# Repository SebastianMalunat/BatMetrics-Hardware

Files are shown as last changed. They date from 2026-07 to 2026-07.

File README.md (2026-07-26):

# BatMetrics — Hardware & Firmware

*Open-source, low-cost hardware and firmware for automated, low-disturbance bat activity monitoring.*



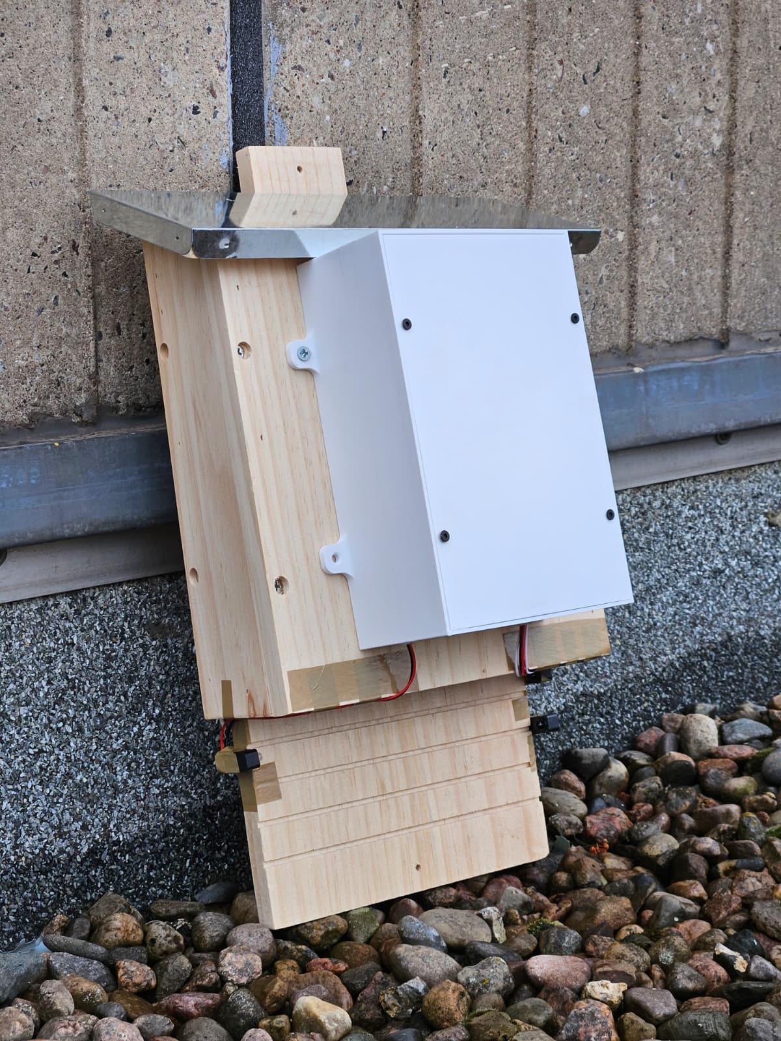
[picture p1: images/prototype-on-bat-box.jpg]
BatMetrics prototype installed on a bat box


## Table of contents

- [Overview](#overview)
- [How it works](#how-it-works)
- [Hardware overview](#hardware-overview)
- [Firmware setup](#firmware-setup)
- [Data & BLE protocol](#data--ble-protocol)
- [Enclosure](#enclosure)
- [Companion app](#companion-app)
- [Limitations](#limitations)
- [License](#license)
- [Acknowledgments](#acknowledgments)

## Overview

BatMetrics is a retrofittable sensor unit for bat boxes. Two infrared beam-break sensors at the box entrance count individual bats entering and leaving, while an onboard temperature and humidity sensor tracks conditions outside the box. Counts and readings are logged to a micro SD card and made available live over Bluetooth Low Energy, so data can be checked and exported without opening the box.

The project aims to make basic bat activity monitoring affordable and accessible to small conservation groups and researchers, in support of UN SDG 15 (Life on Land).

This repository holds the hardware design and Arduino firmware. For the mobile-friendly dashboard that syncs with it, see the [BatMetrics app repository](https://github.com/antoniabuss/bat-metrics-application).

## How it works

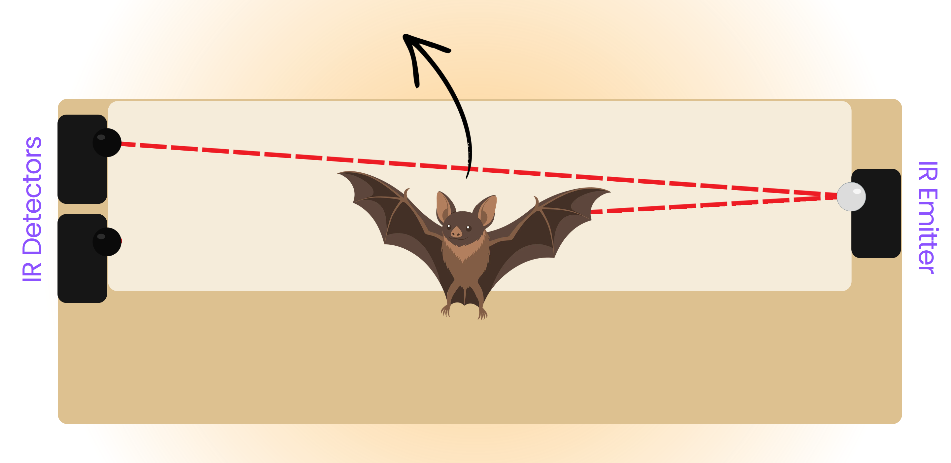
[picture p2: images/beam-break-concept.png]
Beam-break counting concept


Two IR receivers are mounted vertically at the box entrance, opposite a single IR emitter operating at 950 nm (outside the visible range for common bat species). Under normal conditions both beams stay unbroken. When a bat crosses, its body interrupts one beam slightly before the other — the order the beams break in determines direction: sensor-1-first is counted as **in**, sensor-2-first as **out**. If both beams break within the same debounced sample (e.g. two bats passing at once), the event is logged separately as **unknown** rather than guessing a direction.

A short per-beam debounce (15 ms, tuned against real bounce measurements) filters out spurious transitions before they're trusted, and a four-state sequence (`IDLE` → `ARMED_1`/`ARMED_2` → `CLEARING`) prevents a single bat lingering at the entrance from being counted twice.

Temperature and humidity are sampled once at boot and then every 15 minutes. Every confirmed crossing and every sensor reading is written to the SD card immediately, and pushed to any connected BLE client without delay.

## Hardware overview

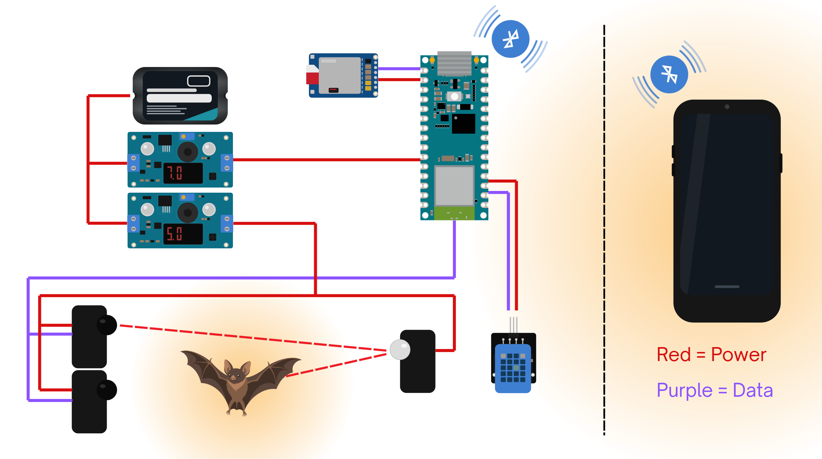
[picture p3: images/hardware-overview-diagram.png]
Hardware overview diagram


*Red = power, purple = data.*

The system has three hardware groups:

- **Sensor array** — two IR beam-break receivers and one IR emitter at the box entrance.
- **Microcontroller & storage** — an Arduino Nano ESP32 reads the sensors, drives BLE, and logs to a micro SD card over SPI.
- **Power supply** — a single 2S Li-ion pack feeds two step-down converters (7 V for the Arduino, 5 V for the IR sensors/emitter).

Full bill of materials, wiring tables, and step-by-step build instructions: **[docs/HARDWARE.md](docs/HARDWARE.md)**.

## Firmware setup

### Requirements

- [Arduino IDE](https://www.arduino.cc/en/software) with the **esp32** board package installed (via Boards Manager)
- Board: **Arduino Nano ESP32**
- Library: **DHT11** (the lightweight library exposing `readTemperatureHumidity()` / `setDelay()` / `getErrorString()` — install via Library Manager and confirm it matches this API before flashing, since multiple same-named DHT libraries with different interfaces exist)
- `SPI`, `SD`, `BLEDevice`, `BLEServer`, `BLEUtils`, `BLE2902` — bundled with the ESP32 board package, no separate install needed
- A micro SD card formatted as **FAT32** (32 GB or smaller — larger cards caused issues during development)

### Flashing

1. Clone this repository:
   ```
   git clone https://github.com/SebastianMalunat/BatMetrics-Hardware.git
   ```
2. Open `batmetrics_firmware.ino` in the Arduino IDE.
3. Select **Tools → Board → Arduino Nano ESP32**.
4. Connect the Arduino via USB-C and select the matching **Port**.
5. Verify/compile, then upload.
6. Open the Serial Monitor at **115200 baud** to see live beam states and counts for debugging.

The BLE device name is set in the `BLEDevice::init(...)` call near the top of `setup()` — rename it (e.g. to identify each deployed box) before flashing your own unit.

## Data & BLE protocol

### SD card snapshot

The current counts and latest environmental reading are written to `/COUNTS.CSV` on every event, overwriting the previous snapshot (not an append-only log):

```
count_in,count_out,count_unknown,net,temperature,humidity,uptime_millis
```

`net` is `count_in - count_out`; `count_unknown` counts crossings where a direction couldn't be reliably assigned.

### BLE characteristic

The Arduino advertises as a BLE peripheral under a configurable name (`BatBox-<name>`) with one service/characteristic pair:

| | UUID |
|---|---|
| Service | `12345678-1234-1234-1234-1234567890ab` |
| Characteristic | `abcd1234-1234-1234-1234-1234567890ab` |

The characteristic supports both **read** (current value) and **notify** (pushed on every counted crossing and every temperature/humidity reading), and holds a compact JSON payload:

```json
{"bats": 12, "temp": 21.5, "hum": 63}
```

`bats` is the net count (`count_in - count_out`). A newly connected client receives an immediate update rather than waiting for the next event.

## Enclosure

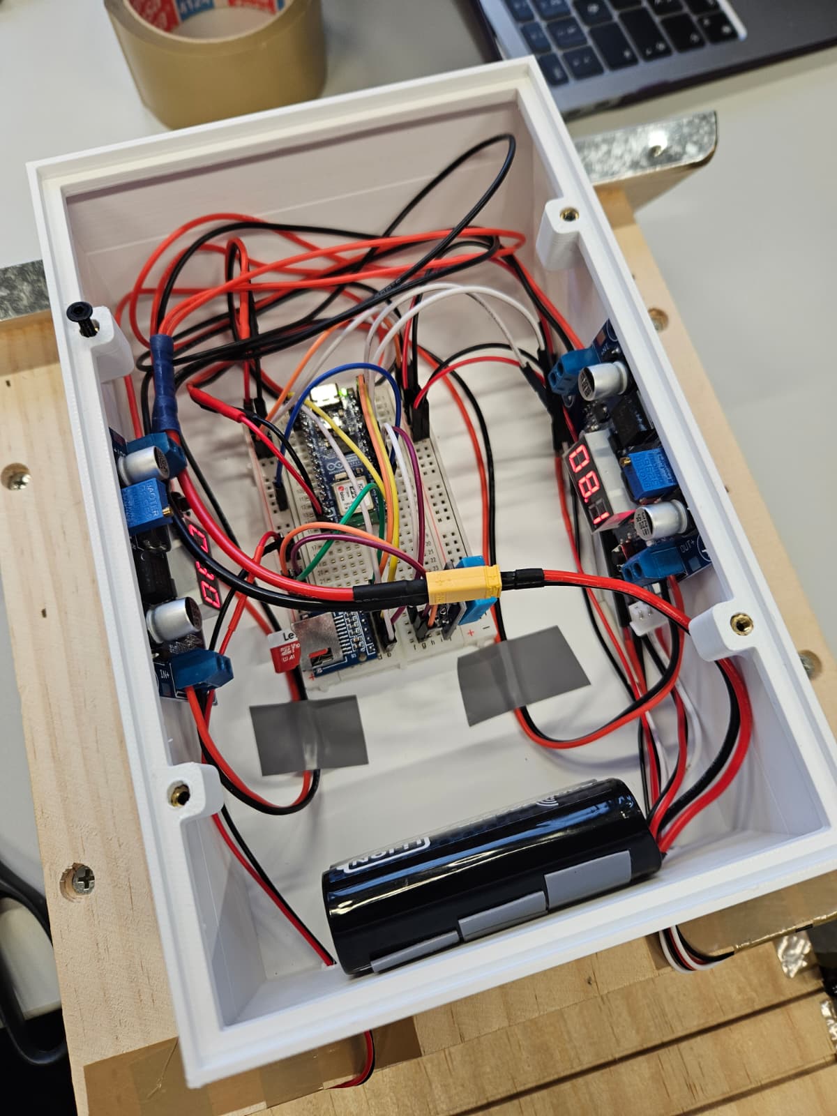
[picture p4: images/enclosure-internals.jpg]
Assembled electronics inside the enclosure

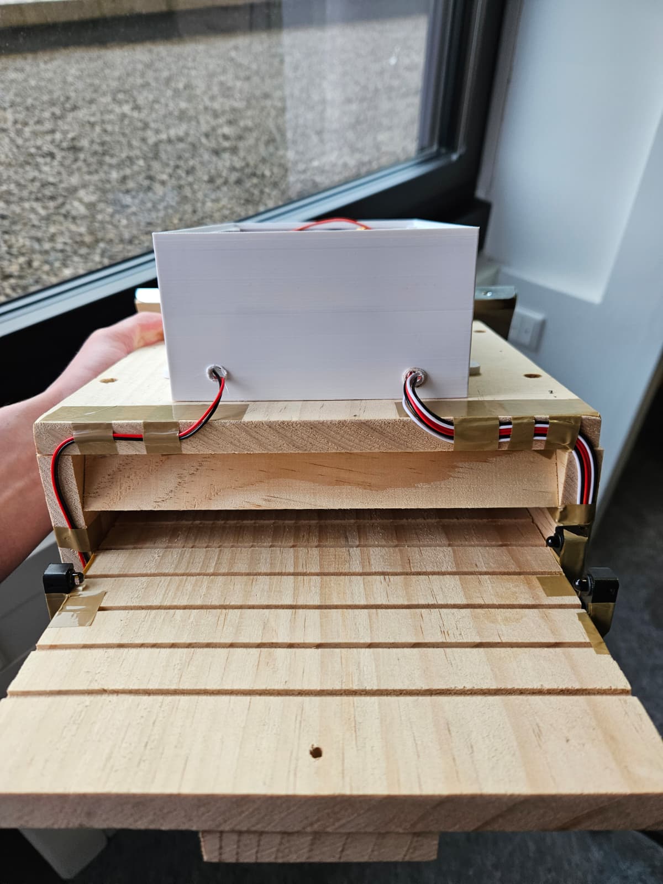
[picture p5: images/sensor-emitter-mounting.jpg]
IR sensor and emitter mounted at the box entrance


The electronics are housed in a 3D-printed, two-part enclosure (body + lid) that mounts directly onto a bat box via four screw tabs. The prototype housing is deliberately oversized to simplify assembly — a production version could be considerably smaller — and future iterations should add weatherproofing (e.g. a rubber seal) and dedicated mounts for the internal electronics, which are currently glued in place.

Source files (`.3mf`) for both parts are in [`enclosure/`](enclosure/); we printed ours in PLA with heat-set inserts for the lid screws. The editable CAD model is available on [Onshape](https://cad.onshape.com/documents/98fc3c93e9cfa1a28dc60713/w/ab1f05b3e45a61a059b0592a/e/94952d4c4642f22f709c8d5e).

## Companion app

The [BatMetrics app](https://github.com/antoniabuss/bat-metrics-application) is the client-side dashboard used to sync a box, view its readings, and export data as CSV. It connects over Web Bluetooth, which restricts it to Chromium-based browsers (Chrome, Edge) — Firefox and Safari aren't supported.

## Limitations

- **Environmental sensing** — the DHT11 sensor is rated 0–50 °C; winter outdoor deployment would need a sensor rated for sub-zero temperatures.
- **Weather resistance** — neither the enclosure nor the IR components are weatherproofed yet; sealing and potted wire passthroughs are needed for permanent outdoor use.
- **Power supply** — the 2S Li-ion pack performed well in testing but doesn't offer the runtime needed for prolonged unattended deployment; a long-runtime, weather-resistant power solution is future work.
- **Step-down converter noise** — the converters used occasionally emit a high-pitched noise that could potentially disturb bats; quieter alternatives should be evaluated.
- **Counting robustness** — validated reliably under lab conditions with two sensors; real-world conditions may be more challenging, and additional sensors could improve robustness.

The companion app has its own set of limitations (no backend, browser-local storage only) — see its [README](https://github.com/antoniabuss/bat-metrics-application#limitations).

## License

This project — including the firmware, hardware design files, and documentation — is licensed under the [MIT License](LICENSE).

## Acknowledgments

Developed as part of the Digital Innovation Lab at Universität Hamburg.

Issues and pull requests are welcome.

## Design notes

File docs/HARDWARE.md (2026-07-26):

# Hardware guide

Full bill of materials, wiring tables, and build instructions for the BatMetrics sensor unit. See the [main README](../README.md) for an overview of how the system works.

Building this requires basic soldering/crimping skills but is approachable for most makers. Total build cost is under €200 for a single unit, or under €150 per unit when building several.

## Table of contents

- [Bill of materials](#bill-of-materials)
- [Wiring tables](#wiring-tables)
- [Build instructions](#build-instructions)

## Bill of materials

| # | Qty | Manufacturer | Part | Description | Approx. cost/unit |
|---|---|---|---|---|---|
| 1 | 1 | Arduino | Nano ESP32 (with headers) | Microcontroller used for the counting system | 22€ |
| 2 | 2 | Adafruit | ADA2168 (5 mm) | IR beam-break sensors | 11€ |
| 3 | 2 | Generic (AZ-Delivery) | LM2596S | Step-down converters | 4€ |
| 4 | 1 | Radiomaster | 2S 21700 5000 mAh Li-ion | Battery | 25€ |
| 5 | 1 set | Generic (GTIWUNG) | Pre-soldered XT30 connector set with cables | Connectors and wires for power distribution | 8€ |
| 6 | 1 set | Generic (QWORK) | 22 AWG silicone wire set | Power cables for distributing power to components | 15€ |
| 7 | 1 set | Generic (ELEGOO) | Jumper cable set | Male-male, male-female, female-female jumper cables | 7€ |
| 8 | 1 | Generic (AZDelivery) | Mini breadboard, 400 pin | Breadboard | 4€ |
| 9 | 1 | Lexar | 32 GB UHS-I, U1, A1, V10, C10 micro SD card | Storage for config and occupancy data | 18€ |
| 10 | 1 | Generic (Create idea) | Micro SD card module, SPI, 3.3 V | Micro SD card module | 2€ |
| 11 | 1 | Generic (AZDelivery) | DHT11 temperature and humidity sensor | Temperature and humidity module | 5€ |
| 12 | 1 | Generic (WILDLIFE HOME) | Large wood bat box, built to NABU standards | Bat box | 30€ |
| 13 | 1 set | Generic | Wood screws | For attaching the 3D-printed housing to the bat box, and the IR emitter/sensors | <10€ |
| 14 | 1 set | Generic (Bolatus) | Heat-set inserts for 3D prints | For securing the housing's lid | 12€ |
| 15 | 1 set | Generic | Machine screw set (metric) | For securing the housing's lid | 11€ |

**Total cost per unit:** < €199
**Total cost per unit (building multiple systems):** < €145

## Wiring tables

### SD card module

| SD card module | Arduino Nano ESP32 |
|---|---|
| GND | Shared ground rail (or GND on the Arduino) |
| MISO | D12 (CIPO / GPIO047) |
| CLK | D13 (SCK / GPIO048) |
| MOSI | D11 (COPI / GPIO038) |
| CS | D4 (GPIO07) |
| 3V3 | 3V3 OUT |

### Temperature and humidity sensor

| DHT11 sensor | Arduino Nano ESP32 |
|---|---|
| I/O | D3 (GPIO06) |
| GND | Shared ground rail (or GND on the Arduino) |
| VCC | 3V3 OUT |

### IR beam-break sensors and emitter

| | IR sensor 1 | IR sensor 2 | IR emitter |
|---|---|---|---|
| 5V | 5V Out step-down converter (V OUT +) | 5V Out step-down converter (V OUT +) | 5V Out step-down converter (V OUT +) |
| GND | V OUT − (or shared ground rail) | V OUT − (or shared ground rail) | V OUT − (or shared ground rail) |
| DATA | Arduino D6 | Arduino D8 | — |

### Step-down converters

| 7V Out converter | Arduino Nano ESP32 |
|---|---|
| V OUT + | VIN |
| V OUT − | GND |

| 7V Out converter | Battery |
|---|---|
| V IN + | V OUT + |
| V IN − | V OUT − |

| 5V Out converter | 5V power rail on breadboard |
|---|---|
| V OUT + | + rail |
| V OUT − | − rail |

| 5V Out converter | Battery |
|---|---|
| V IN + | V OUT + |
| V IN − | V OUT − |

## Build instructions

Soldering and crimping are recommended for reliable connections; jumper cables and pin headers are usable for testing or to lower the barrier to entry (our prototype relies heavily on jumper cables to keep soldering to a minimum). Anyone building this system for actual deployment should replace jumper connections with soldered joints, crimps, or other more durable connections.

### Enclosure prep

1. 3D print the enclosure (we used PLA) — source files are in [`../enclosure/`](../enclosure/).
2. Drill one or two holes in the underside of the enclosure to pass the wires for the IR emitter and sensors through.
3. Install the four heat-set inserts into the corresponding holes in the print.
4. Glue the breadboard into the enclosure using its adhesive backing.
5. Glue the step-down converters to the inside of the enclosure. Future iterations should mount these more securely, e.g. with heat-set inserts and screws.

### Power wiring

Assembled electronics inside the enclosure

6. Build a power splitter cable by crimping a pre-soldered male XT30 connector to two red and two black silicone wires, so each wire from the connector splits into two. Tin the free ends to ease insertion into the step-down converters' terminals.
7. Connect one red/black pair from the splitter to the input of each step-down converter, following the wiring tables above.
8. Set one converter to output 7 V and the other 5 V. If the converters have a display, switch it to show output voltage and adjust the potentiometer accordingly; otherwise connect a battery to the input and adjust the potentiometer while measuring output with a multimeter. Labelling the underside of each converter helps keep track of which is which.
9. Solder jumper connectors to one end of two red and two black wire lengths, and tin the other ends.
10. Connect the 7 V converter's output to the Arduino and the ground rail using these wires.
11. Connect the 5 V converter's output to one of the breadboard's power rails using the second set of wires — this rail supplies 5 V to the remaining components and serves as the shared ground.

### Electronics and sensors

12. Place the Arduino on the breadboard, leaving enough space for the micro SD card module and the temperature/humidity sensor.
13. Place the micro SD card module on the breadboard and wire it per the table above.
14. Format the micro SD card as FAT32 and insert it into the module. Cards larger than 32 GB caused issues for us and should be avoided.
15. Place the temperature and humidity sensor on the breadboard and wire it per the table above.
16. Strip the wire ends of the IR emitter and both IR sensors, and solder jumper connectors onto each — we recommend covering the joints with heat shrink to prevent shorts. In a production build these should be wired directly to the Arduino, with leads extended as needed for the target bat box.

IR sensor and emitter mounted at the box entrance

17. Mount the IR emitter and both sensors at the entrance of the bat box, emitter on one side and both sensors on the other (e.g. sensors on the left, emitter on the right) — all three come with screw holes for this. Space the sensors approximately 3.5 cm apart vertically, measured at the sensor itself, to improve counting reliability.
18. Wire the IR emitter and both sensors to the Arduino and step-down converter per the table above.

### Firmware, assembly & testing

19. Clone this repository, install the required libraries (see the [main README](../README.md#requirements)), and compile/upload the firmware via the Arduino IDE.
20. Place the battery inside the enclosure and secure it (we used electrical tape).
21. Connect the battery's XT30 connector to the splitter's XT30 connector — the system should power up and begin counting.
22. Fit the lid and fasten the retaining screws.
23. Confirm proper operation by testing the Bluetooth connection with the app. Simulate bat crossings by hand at the entrance and verify the count updates correctly both in the app and on the micro SD card.

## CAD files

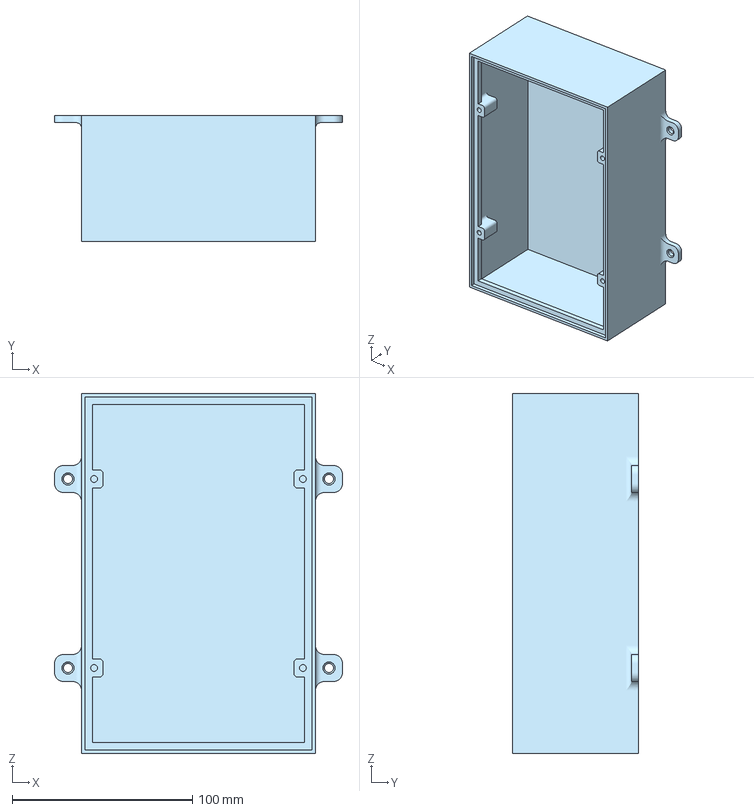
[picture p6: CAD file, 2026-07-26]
enclosure/BatMetrics Prototype Enclosure - Body.3mf
160.0 x 70.0 x 200.0 mm

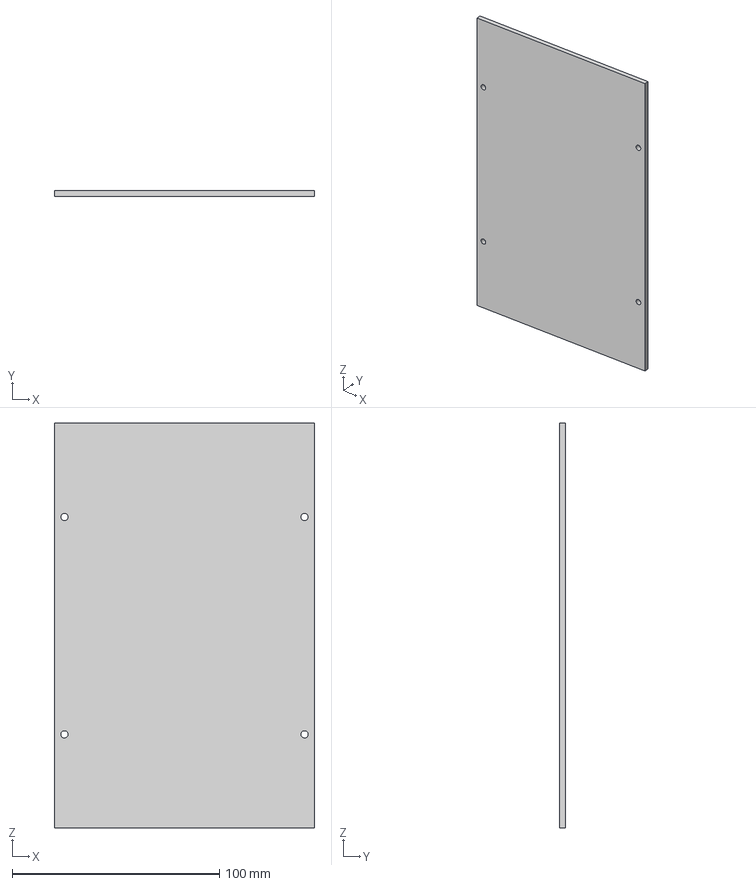
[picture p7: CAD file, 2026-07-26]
enclosure/BatMetrics Prototype Enclosure - Lid.3mf
125.6 x 3.00 x 195.6 mm

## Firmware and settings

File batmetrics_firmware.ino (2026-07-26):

#include <DHT11.h>
#include <SPI.h>
#include <SD.h>
#include <BLEDevice.h>
#include <BLEServer.h>
#include <BLEUtils.h>
#include <BLE2902.h>

// --- Pin assignments ---
const int pin_ir_receiver_1 = D6;
const int pin_ir_receiver_2 = D8;
const int pin_temp_humidity = D3;
const int pin_sd_cs = 4;

// Per-beam causal debounce; validated safe range 15-20ms (real bounce found at
// 1-49ms, genuine pulses never shorter than ~38ms once debounced).
const unsigned long DEBOUNCE_MS = 15;

const char *SNAPSHOT_PATH = "/COUNTS.CSV";

// --- BLE ---
#define SERVICE_UUID        "12345678-1234-1234-1234-1234567890ab"
#define CHARACTERISTIC_UUID "abcd1234-1234-1234-1234-1234567890ab"

BLECharacteristic *pChar;
bool ble_connected = false;
// Set on the BLE stack's own task in onConnect(); read/cleared from loop() so
// the first notify to a newly connected client is sent from the main loop,
// not synchronously inside the connect callback -- a client typically hasn't
// written the notify-subscribe (CCCD) descriptor yet at the exact moment
// onConnect fires, so a notify() sent right there is commonly dropped.
volatile bool ble_just_connected = false;

class ServerCB : public BLEServerCallbacks {
  void onConnect(BLEServer *s) {
    ble_connected = true;
    ble_just_connected = true;
  }
  void onDisconnect(BLEServer *s) {
    ble_connected = false;
    s->startAdvertising();
  }
};

float temperature = 999.99;
int humidity = 0;
int temperature_humidity_readout_interval_minutes = 15;
unsigned long int temperature_humidity_readout_millis = 0;

DHT11 dht11(pin_temp_humidity);

unsigned long int prMillis = 0;


// Debounces a single digital input: a new raw value is only accepted as the
// real `debounced` state once it has been stable for DEBOUNCE_MS.
struct DebouncedInput {
  bool raw_last;
  bool debounced;
  unsigned long last_change_millis;

  void init(bool initial) {
    raw_last = debounced = initial;
    last_change_millis = millis();
  }

  void update(bool raw) {
    unsigned long now = millis();
    if (raw != raw_last) {
      raw_last = raw;
      last_change_millis = now;
    }
    if (raw != debounced && (now - last_change_millis) >= DEBOUNCE_MS) {
      debounced = raw;
    }
  }
};

DebouncedInput barrier1;  // debounced == true means "closed", i.e. beam intact
DebouncedInput barrier2;

enum CounterState { IDLE, ARMED_1, ARMED_2, CLEARING };
CounterState counter_state = IDLE;
bool prev_b1_closed = true;
bool prev_b2_closed = true;

long count_in = 0;       // barrier1-first ("1-first")
long count_out = 0;      // barrier2-first ("2-first")
long count_unknown = 0;  // both beams broke in the same debounced sample
int last_direction = 0;  // 0=none, +1=IN, -1=OUT, 2=unknown (Serial diagnostics only)


void write_sd_snapshot() {
  SD.remove(SNAPSHOT_PATH);
  File dataFile = SD.open(SNAPSHOT_PATH, FILE_WRITE);
  if (dataFile) {
    dataFile.println("count_in,count_out,count_unknown,net,temperature,humidity,uptime_millis");
    dataFile.print(count_in);
    dataFile.print(",");
    dataFile.print(count_out);
    dataFile.print(",");
    dataFile.print(count_unknown);
    dataFile.print(",");
    dataFile.print(count_in - count_out);
    dataFile.print(",");
    dataFile.print(temperature);
    dataFile.print(",");
    dataFile.print(humidity);
    dataFile.print(",");
    dataFile.print(millis());
    dataFile.print("\n");
    dataFile.close();
  } else {
    Serial.println("Error while opening snapshot file for write.");
  }
}


bool read_sd_snapshot() {
  File dataFile = SD.open(SNAPSHOT_PATH, FILE_READ);
  if (!dataFile) {
    Serial.println("No snapshot file found -- starting counts at 0.");
    return false;
  }
  dataFile.readStringUntil('\n');  // discard header
  String row = dataFile.readStringUntil('\n');
  dataFile.close();
  row.trim();

  int p1 = row.indexOf(',');
  int p2 = row.indexOf(',', p1 + 1);
  int p3 = row.indexOf(',', p2 + 1);  // net column boundary; value recomputed, not trusted
  int p4 = row.indexOf(',', p3 + 1);
  int p5 = row.indexOf(',', p4 + 1);
  if (p1 < 0 || p2 < 0 || p3 < 0 || p4 < 0 || p5 < 0) {
    Serial.println("Snapshot file malformed -- starting counts at 0.");
    return false;
  }

  count_in = row.substring(0, p1).toInt();
  count_out = row.substring(p1 + 1, p2).toInt();
  count_unknown = row.substring(p2 + 1, p3).toInt();
  temperature = row.substring(p4 + 1, p5).toFloat();
  humidity = row.substring(p5 + 1).toInt();

  Serial.print("Restored from snapshot: count_in=");
  Serial.print(count_in);
  Serial.print(" count_out=");
  Serial.print(count_out);
  Serial.print(" count_unknown=");
  Serial.println(count_unknown);
  return true;
}


// Always refreshes the characteristic's stored value (cheap, no BLE traffic),
// so a client that does a plain GATT read right after connecting -- instead
// of or before subscribing to notifications -- still gets current data rather
// than whatever was last notified (or nothing, on a fresh boot with no
// bat/DHT events yet).
void update_ble_value() {
  char json[64];
  snprintf(json, sizeof(json), "{\"bats\":%d,\"temp\":%.1f,\"hum\":%d}",
           (int)(count_in - count_out), temperature, humidity);
  pChar->setValue(json);
}

void notify_ble() {
  update_ble_value();
  if (ble_connected) {
    pChar->notify();
  }
}


void count_ir_barriers_logic() {
  barrier1.update(digitalRead(pin_ir_receiver_1) == 1);
  barrier2.update(digitalRead(pin_ir_receiver_2) == 1);

  bool cur_b1 = barrier1.debounced;
  bool cur_b2 = barrier2.debounced;

  bool b1_broke = prev_b1_closed && !cur_b1;
  bool b1_released = !prev_b1_closed && cur_b1;
  bool b2_broke = prev_b2_closed && !cur_b2;
  bool b2_released = !prev_b2_closed && cur_b2;

  switch (counter_state) {
    case IDLE:
      if (b1_broke && b2_broke) {
        count_unknown++;
        last_direction = 2;
        write_sd_snapshot();
        notify_ble();
        counter_state = CLEARING;
      } else if (b1_broke) {
        counter_state = ARMED_1;
      } else if (b2_broke) {
        counter_state = ARMED_2;
      }
      break;

    case ARMED_1:  // completion checked before abort
      if (b2_broke) {
        count_in++;
        last_direction = 1;
        write_sd_snapshot();
        notify_ble();
        counter_state = CLEARING;
      } else if (b1_released) {
        counter_state = IDLE;  // abort, no count
      }
      break;

    case ARMED_2:
      if (b1_broke) {
        count_out++;
        last_direction = -1;
        write_sd_snapshot();
        notify_ble();
        counter_state = CLEARING;
      } else if (b2_released) {
        counter_state = IDLE;
      }
      break;

    case CLEARING:  // no settle timer -- proven sufficient on real data
      if (cur_b1 && cur_b2) {
        counter_state = IDLE;
      }
      break;
  }

  prev_b1_closed = cur_b1;
  prev_b2_closed = cur_b2;
}


void read_temperature_humidity_sensor() {
  int current_temperature = 0;
  int current_humidity = 0;
  int result = dht11.readTemperatureHumidity(current_temperature, current_humidity);

  if (result == 0) {
    temperature = current_temperature;
    humidity = current_humidity;
  } else {
    Serial.println(DHT11::getErrorString(result));
  }
}


void setup() {
  Serial.begin(115200);

  delay(2000);

  pinMode(pin_ir_receiver_1, INPUT_PULLUP);
  pinMode(pin_ir_receiver_2, INPUT_PULLUP);

  if (!SD.begin(pin_sd_cs)) {
    Serial.println("SD board initialization failed! Counts will not persist across reboots.");
  } else {
    read_sd_snapshot();  // auto-resume; falls back to zeros internally on missing/malformed file
  }

  dht11.setDelay(1000);
  read_temperature_humidity_sensor();
  temperature_humidity_readout_millis = millis();

  barrier1.init(digitalRead(pin_ir_receiver_1) == 1);
  barrier2.init(digitalRead(pin_ir_receiver_2) == 1);
  prev_b1_closed = barrier1.debounced;
  prev_b2_closed = barrier2.debounced;

  prMillis = millis();

  BLEDevice::init("BatBox-Planten-un-Blomen");

  BLEServer *server = BLEDevice::createServer();
  server->setCallbacks(new ServerCB());

  BLEService *service = server->createService(SERVICE_UUID);
  pChar = service->createCharacteristic(
      CHARACTERISTIC_UUID,
      BLECharacteristic::PROPERTY_READ | BLECharacteristic::PROPERTY_NOTIFY);
  pChar->addDescriptor(new BLE2902());  // required for notifications
  service->start();

  BLEAdvertising *adv = server->getAdvertising();
  adv->addServiceUUID(SERVICE_UUID);
  // Longer advertising interval saves power (values are in units of 0.625ms)
  adv->setMinInterval(0x100);  // ~160ms
  adv->setMaxInterval(0x200);  // ~320ms
  adv->start();

  update_ble_value();  // prime the characteristic before any client ever connects
}


void loop() {
  count_ir_barriers_logic();  // unthrottled, no delay()

  // A loop() that never yields at all can starve the ESP32 idle task, which
  // trips the task watchdog and reboots the chip -- looking like a random BLE
  // disconnect. A 1ms yield every ~20ms costs ~5% of the polling budget at
  // most (still comfortably above the validated ~610-915Hz floor) and is
  // rate-limited so it doesn't throttle every single iteration.
  static unsigned long lastYieldMillis = 0;
  if (millis() - lastYieldMillis >= 20) {
    lastYieldMillis = millis();
    delay(1);
  }

  if (ble_just_connected) {
    ble_just_connected = false;
    notify_ble();  // catch the client up immediately, don't wait for the next bat pass or DHT tick
  }

  if (millis() - temperature_humidity_readout_millis >= temperature_humidity_readout_interval_minutes * 60 * 1000) {
    temperature_humidity_readout_millis = millis();
    read_temperature_humidity_sensor();
    write_sd_snapshot();
    notify_ble();
  }

  // Arduino Nano ESP32 uses native USB CDC for Serial, not a separate USB-
  // serial chip: if nothing is actively reading it (Serial Monitor closed, or
  // running standalone on battery), Serial.print() can block once its
  // internal buffer fills, stalling loop() indefinitely. `if (Serial)` is
  // true only while a host actually has the CDC port open.
  if (Serial && millis() - prMillis >= 400) {
    prMillis = millis();

    Serial.print(millis());
    Serial.print("ms B1:");
    Serial.print(barrier1.debounced ? "C" : "O");
    Serial.print(" B2:");
    Serial.print(barrier2.debounced ? "C" : "O");
    Serial.print(" state=");
    Serial.print(counter_state);
    Serial.print(" IN=");
    Serial.print(count_in);
    Serial.print(" OUT=");
    Serial.print(count_out);
    Serial.print(" UNK=");
    Serial.print(count_unknown);
    Serial.print(" NET=");
    Serial.print(count_in - count_out);
    Serial.print(" last=");
    Serial.print(last_direction == 1 ? "IN" : last_direction == -1 ? "OUT" : last_direction == 2 ? "UNK" : "-");
    Serial.print(" T=");
    Serial.print(temperature);
    Serial.print("C H=");
    Serial.print(humidity);
    Serial.print("% BLE=");
    Serial.println(ble_connected ? "connected" : "-");
  }
}

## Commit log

2026-07-26 feat(enclosure): add 3D-printable enclosure design files
    [BatMetrics Prototype Enclosure - Body.3mf, BatMetrics Prototype Enclosure - Lid.3mf]
2026-07-26 docs(hardware): add prototype photos and diagrams
2026-07-26 docs: link Onshape CAD document for enclosure

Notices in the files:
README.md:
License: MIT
